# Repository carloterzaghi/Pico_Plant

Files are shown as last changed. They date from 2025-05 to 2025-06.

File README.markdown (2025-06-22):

# Sistema de Irrigação Inteligente com Raspberry Pi Pico

Um sistema embarcado para monitoramento de umidade do solo e controle automatizado de irrigação, utilizando o microcontrolador Raspberry Pi Pico.

## Visão Geral

Este projeto visa criar um sistema de irrigação eficiente e autônomo para plantas, especialmente projetado para uso doméstico ou em pequenos cultivos. Ele utiliza um sensor de umidade do solo capacitivo, criado previamente para somente esse projeto, para detectar o nível de umidade do solo e acionar uma bomba d'água conforme a necessidade. O sistema é construído sobre o Raspberry Pi Pico e programado em C/C++ utilizando o Pico SDK.

## Funcionalidades

* **Monitoramento Contínuo da Umidade do Solo**: Lê a tensão do sensor de umidade do solo a cada segundo para determinar o nível de umidade.
* **Controle Inteligente da Bomba D'água**: Ativa ou desativa a bomba automaticamente conforme o estado do solo, com lógica baseada em limiares de tensão.
* **Irrigação Otimizada**: Mantém a bomba ligada por 9 segundos quando necessário para garantir a hidratação adequada do solo.
* **Prevenção de Comandos Repetidos**: Uma *flag* (`motor_desligado`) evita o envio de comandos desnecessários à bomba, aumentando a eficiência e durabilidade.
* **Alimentação Estável do Sensor**: Utiliza PWM (Pulse Width Modulation) configurado com 100% de *duty cycle* no GPIO 2 para fornecer uma alimentação de 3.3V estáveis ao sensor de umidade, garantindo leituras precisas.
* **Comunicação Serial USB**: Fornece *feedback* em tempo real das leituras do sensor via comunicação serial para fins de depuração e monitoramento.
* **Feedback Visual**: Mostra rostos felizes ou tristes em um display OLED conforme o estado do solo.

## Hardware

### Esquema Elétrico do Controlador de Irrigação Inteligente
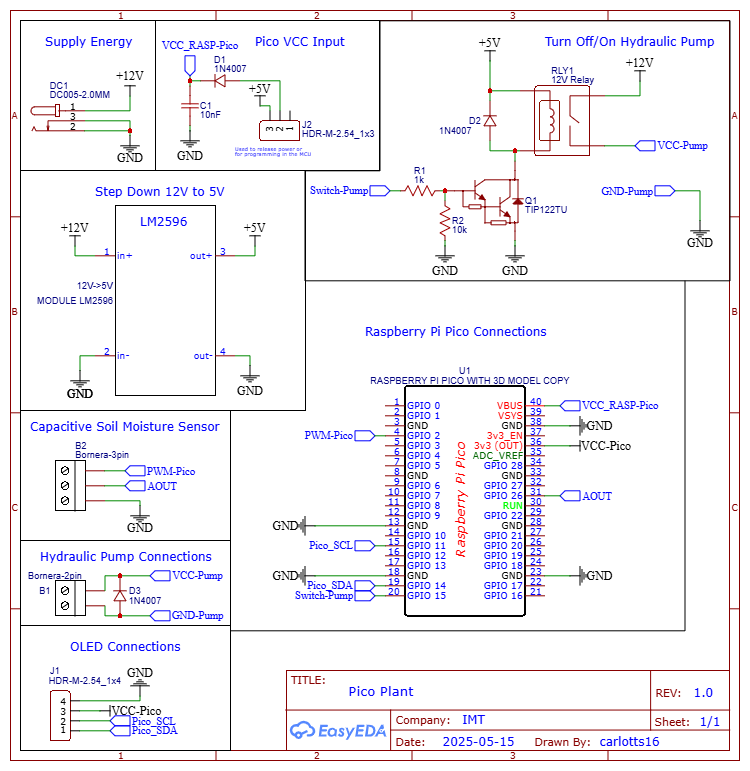
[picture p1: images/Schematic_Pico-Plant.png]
Esquema elétrico do controlador


### Exemplo de PCB do Controlador
#### Top Layer
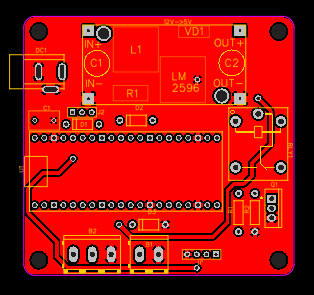
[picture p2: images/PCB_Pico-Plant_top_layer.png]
PCB Top Layer do controlador


#### Bottom Layer
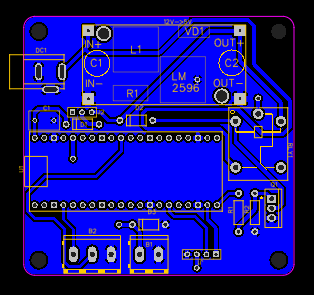
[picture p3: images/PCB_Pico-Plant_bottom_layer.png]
PCB Bottom Layer do controlador


### Esquema Elétrico do Sensor Capacitivo de Umidade do Solo
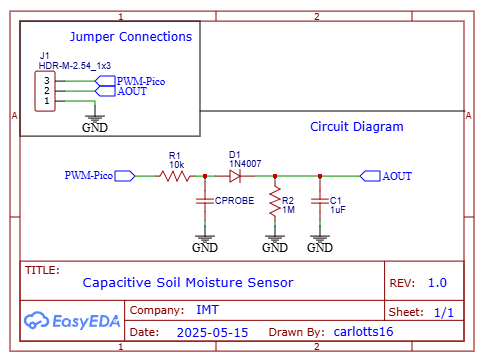
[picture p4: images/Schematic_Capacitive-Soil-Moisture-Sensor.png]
Esquema elétrico do sensor


### Exemplo de PCB do Sensor Capacitivo
#### Bottom Layer
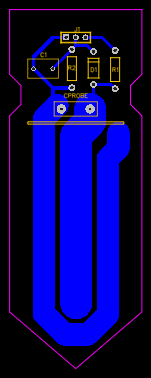
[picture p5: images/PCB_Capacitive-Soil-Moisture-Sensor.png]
PCB Bottom Layer do sensor


## Estrutura do Projeto

* `CMakeLists.txt`: Arquivo de configuração do CMake para construir o projeto.
* `main.c`: Contém a lógica principal do sistema, incluindo a inicialização, leitura do ADC, controle da bomba e exibição no OLED.
* `auxiliary_codes/pwm_code.c`: Implementa a função de configuração do PWM para alimentar o sensor.
* `auxiliary_codes/pwm_code.h`: Declaração da função de configuração do PWM.

## Lógica de Operação Detalhada

O sistema opera com base na leitura da tensão do sensor de umidade do solo, convertida pelo ADC do Raspberry Pi Pico. A lógica de irrigação é baseada em três faixas principais de tensão, conforme dados experimentais e a lógica implementada no código:

* **Valores de Referência**:
    * **Solo Muito Úmido**: Tensão < 0.58V **e** `motor_desligado == 0`
        * **Ação**: Liga a bomba por 9 segundos, mostra rosto triste no OLED.
    * **Solo Úmido**: Tensão >= 0.58V
        * **Ação**: Desliga a bomba, mostra rosto feliz no OLED, evita desligamento repetido (seta `motor_desligado = 1`).
    * **Solo Seco**: Tensão < 1.44V
        * **Ação**: Liga a bomba por 9 segundos, mostra rosto triste no OLED, libera novo ciclo (seta `motor_desligado = 0`).

* **Tabela de Referência da Umidade do Solo**:

| Tensão (V) | Água (mL) | Estado |
|---|---|---|
| 3.11-1.66  | 0-11 | Seco |
| 1.44-0.58  | 12-20 | Úmido Adequado |
| V <= 0.54  | mL >= 21  | Muito Úmido |

*Dados coletados:*

Materiais utilizados: `copo com 84757,03 mm^3` e `seringa com medidas de 1 em 1 mL`.

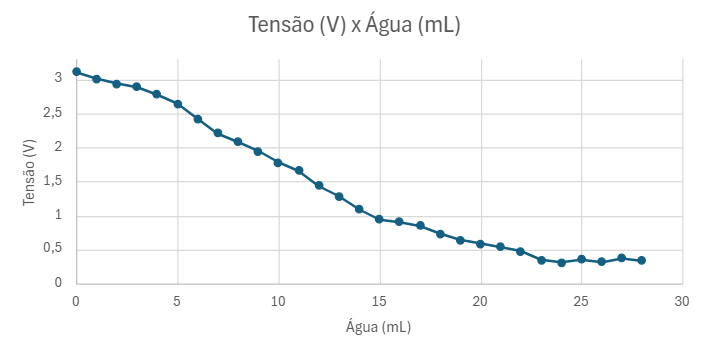
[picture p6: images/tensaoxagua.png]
Gráfico Tensão (V) x Água (mL)

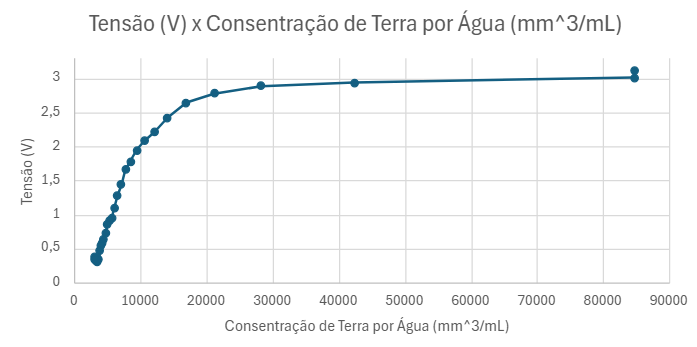
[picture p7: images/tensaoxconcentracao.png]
Gráfico Tensão (V) x Consentração de Terra por Água (mm^3/mL)


* **Prevenção de Ciclos**:  
A flag `motor_desligado` evita comandos repetidos de desligamento da bomba, melhorando a eficiência e durabilidade do sistema.

---

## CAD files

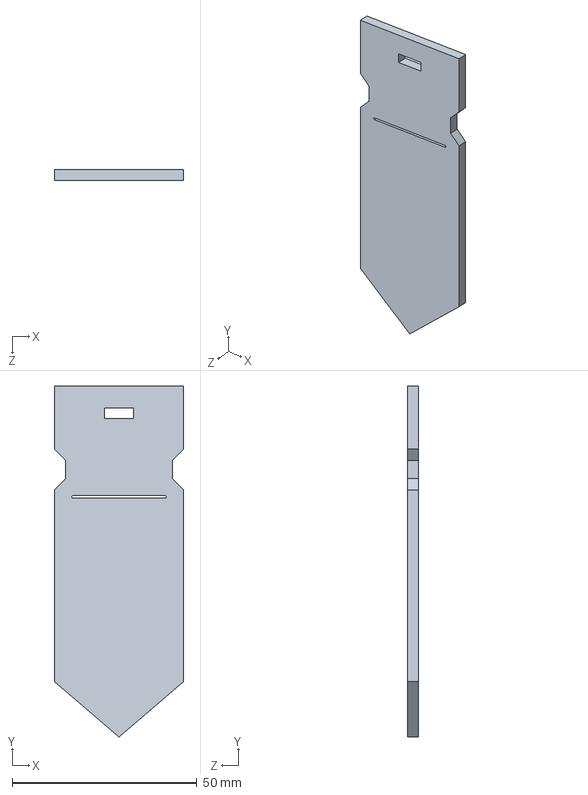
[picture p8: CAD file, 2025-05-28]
solid-parts/eletronic/PCB - Capacitive Soil Moisture Sensor.SLDPRT
35.0 x 95.0 x 3.00 mm

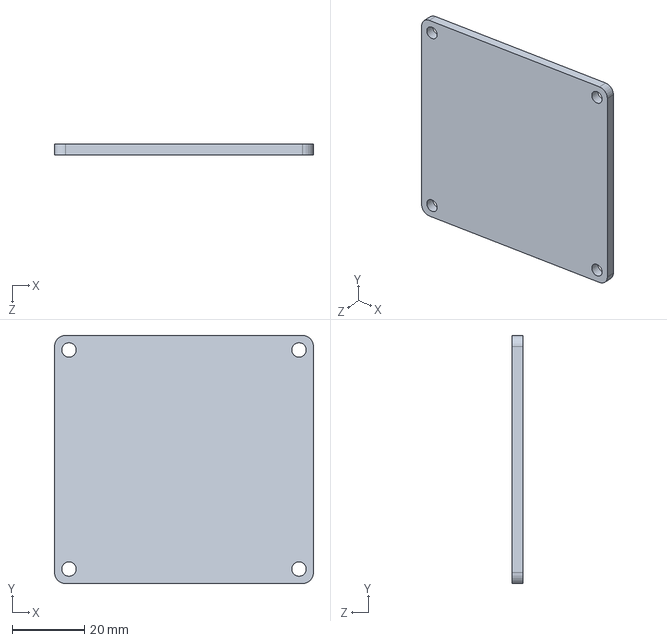
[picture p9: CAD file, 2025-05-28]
solid-parts/eletronic/PCB-Pico-Plant.SLDPRT
71.5 x 68.5 x 3.00 mm

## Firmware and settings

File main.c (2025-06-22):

// ===== INCLUSÃO DE BIBLIOTECAS =====
#include "pico/stdlib.h"                    // Funções básicas do Raspberry Pi Pico
#include "hardware/adc.h"                   // Interface para uso do ADC
#include "auxiliary_codes/pwm_code.h"       // Controle de alimentação via PWM
#include <stdio.h>                          // Entrada e saída padrão
#include "hardware/i2c.h"                   // Comunicação I2C
#include "hardware/gpio.h"                  // Controle de GPIOs
#include "auxiliary_codes/oled_ssd1306.h"   // Funções gráficas para display OLED

// ===== Definições de Hardware =====
#define SENSOR_ADC_GPIO 26     // GPIO 26 - Entrada analógica (ADC0) para sensor de umidade
#define SENSOR_PWR_GPIO 2      // GPIO 2  - Saída PWM para alimentação do sensor
#define PUMP_GPIO 15           // GPIO 15 - Saída digital para controle da bomba d'água
#define I2C_SDA 14             // GPIO 14 - Linha de dados I2C
#define I2C_SCL 11             // GPIO 11 - Linha de clock I2C

// ===== Parâmetros de Sistema =====
#define SOIL_MIN_VOLTAGE 1.44f      // Tensão mínima: >1.44V = mínimo para o solo estar úmido, depois do seco
#define SOIL_MAX_VOLTAGE 0.58f      // Tensão máxima: <0.58V = máximo para o solo estar úmido, antes de ficar muito úmido e não matar a planta

int main() {
    // === Inicialização do Sistema ===
    stdio_init_all();                      // Comunicação serial via USB
    printf("Inicializando faces animadas...\n");

    // --- Inicialização do barramento I2C ---
    i2c_init(I2C_PORT, 100 * 1000);        // Frequência I2C = 100kHz
    gpio_set_function(I2C_SDA, GPIO_FUNC_I2C);
    gpio_set_function(I2C_SCL, GPIO_FUNC_I2C);
    gpio_pull_up(I2C_SDA);                 // Pull-ups necessários para I2C
    gpio_pull_up(I2C_SCL);

    // --- Inicialização do Display OLED ---
    printf("Inicializando OLED...\n");
    sleep_ms(100);
    oled_init();
    printf("OLED inicializado! Iniciando animação...\n");

    // === Configuração de Hardware ===

    // --- Alimentação do sensor por PWM ---
    setup_pwm_power(SENSOR_PWR_GPIO);      // Estabiliza 3.3V via PWM para sensor analógico

    // --- Controle da bomba d'água ---
    gpio_init(PUMP_GPIO);                  
    gpio_set_dir(PUMP_GPIO, GPIO_OUT);     // Configura GPIO como saída

    // --- Inicialização do ADC ---
    adc_init();                            
    adc_gpio_init(SENSOR_ADC_GPIO);        // Ativa função analógica no GPIO 26
    adc_select_input(0);                   // Seleciona canal 0 do ADC

    // === Controle Inteligente ===
    int motor_desligado = 0;               // Flag de estado da bomba
                                           // 0 = bomba pode ser ligada
                                           // 1 = bomba já foi desligada após solo umedecido

    // === Loop Principal ===
    while (true) {
        // --- Leitura do sensor ---
        uint16_t leitura = adc_read();
        float tensao = leitura * 3.3f / 4095.0f; 
        printf("Leitura ADC: %d\tTensão: %.2f V\n", leitura, tensao);

        // --- Lógica de Irrigação ---
        if (tensao < SOIL_MAX_VOLTAGE && motor_desligado == 0) {
            // Condição: Menor que 0.58V e bomba não foi desligada
            printf("Mostrando rosto triste :(\n");
            draw_sad_face();                      // Exibe rosto triste no OLED
            gpio_put(PUMP_GPIO, 1);               // Liga a bomba
            sleep_ms(9000);                       // Irriga por 9 segundos
        } 
        else if (tensao >= SOIL_MAX_VOLTAGE) {
            // Condição: Maior ou igual a 0.58V
            printf("Mostrando rosto feliz :)\n");
            draw_happy_face();                    // Exibe rosto feliz no OLED
            gpio_put(PUMP_GPIO, 0);               // Desliga a bomba
            motor_desligado = 1;                  // Evita desligamento repetido
        }
        else if (tensao < SOIL_MIN_VOLTAGE) {
            // Condição: Menor que 1.44V
            printf("Mostrando rosto triste :(\n");
            draw_sad_face();                      // Exibe rosto triste no OLED
            motor_desligado = 0;
            gpio_put(PUMP_GPIO, 1);               // Liga a bomba
            sleep_ms(9000);                       // Irriga por 9 segundos
        }

        // Aguarda 1 segundo antes da próxima leitura
        sleep_ms(1000);                           
    }

    return 0;
}

/*
 * ===== RESUMO DO FUNCIONAMENTO =====
 * 
 * 1. INICIALIZAÇÃO:
 *    - PWM no GPIO 2 alimenta sensor de umidade
 *    - GPIO 15 configurado para controlar bomba
 *    - ADC configurado para ler GPIO 26
 * 
 * 2. CICLO DE MONITORAMENTO (a cada 1 segundo):
 *    - Lê tensão do sensor (0-3.3V)
 *    - Compara com os limiares definidos
 *    - Controla bomba e exibe rosto no OLED conforme a umidade
 * 
 * 3. ESTADOS DO SISTEMA (baseado na lógica atual):
 *    - SOLO MUITO ÚMIDO (tensão < 0.58V e motor_desligado == 0): Liga bomba por 9 segundos, mostra rosto triste
 *    - SOLO ÚMIDO (tensão >= 0.58V): Desliga bomba, mostra rosto feliz, evita desligamento repetido
 *    - SOLO SECO (tensão > 1.44V): Liga bomba por 9 segundos, mostra rosto triste, permite novo ciclo
 * 
 * 4. PREVENÇÃO DE CICLOS:
 *    - Flag 'motor_desligado' evita comandos repetidos de desligamento da bomba
 *    - Melhora eficiência e durabilidade do sistema
 * 
 * ===== TABELA DE REFERÊNCIA (Baseada em dados experimentais) =====
 * 
 * | Tensão (V) | Água (mL) | Estado           |
 * |------------|-----------|------------------|
 * | 3.11-1.66  | 0-11      | Seco             |
 * | 1.44-0.58  | 12-20     | Úmido Adequado   |
 * | V <= 0.54  | mL >= 21  | Muito Úmido      |
 * 
 * O sistema considera:
 * - SOLO MUITO ÚMIDO:     tensão < 0.58V e motor_desligado == 0 (bomba ON)
 * - SOLO ÚMIDO:           tensão >= 0.58V (bomba OFF)
 * - SOLO SECO:            tensão < 1.44V (bomba ON, libera novo ciclo)
 */

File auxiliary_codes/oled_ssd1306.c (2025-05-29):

#include "oled_ssd1306.h"
#include "hardware/i2c.h"
#include <string.h> 
#include <stdlib.h>   
#include <math.h>


// Buffer do display
static uint8_t oled_buffer[OLED_WIDTH * OLED_PAGES];

// Função para enviar comando
void oled_send_cmd(uint8_t cmd) {
    uint8_t buf[2] = {0x00, cmd};
    i2c_write_blocking(I2C_PORT, I2C_ADDR, buf, 2, false);
}

// Função para enviar dados
void oled_send_data(uint8_t *data, size_t len) {
    uint8_t buf[len + 1];
    buf[0] = 0x40;  // Data mode
    memcpy(buf + 1, data, len);
    i2c_write_blocking(I2C_PORT, I2C_ADDR, buf, len + 1, false);
}

// Inicializar o display
void oled_init() {
    oled_send_cmd(SSD1306_DISPLAY_OFF);
    oled_send_cmd(SSD1306_SET_DISPLAY_CLOCK_DIV);
    oled_send_cmd(0x80);
    oled_send_cmd(SSD1306_SET_MULTIPLEX);
    oled_send_cmd(OLED_HEIGHT - 1);
    oled_send_cmd(SSD1306_SET_DISPLAY_OFFSET);
    oled_send_cmd(0x00);
    oled_send_cmd(SSD1306_SET_START_LINE | 0x00);
    oled_send_cmd(SSD1306_CHARGE_PUMP);
    oled_send_cmd(0x14);
    oled_send_cmd(SSD1306_MEMORY_MODE);
    oled_send_cmd(0x00);
    oled_send_cmd(SSD1306_SEG_REMAP | 0x01);
    oled_send_cmd(SSD1306_COM_SCAN_DEC);
    oled_send_cmd(SSD1306_SET_COM_PINS);
    oled_send_cmd(0x12);
    oled_send_cmd(SSD1306_SET_CONTRAST);
    oled_send_cmd(0xCF);
    oled_send_cmd(SSD1306_SET_PRECHARGE);
    oled_send_cmd(0xF1);
    oled_send_cmd(SSD1306_SET_VCOM_DETECT);
    oled_send_cmd(0x40);
    oled_send_cmd(SSD1306_DISPLAY_ALL_ON_RESUME);
    oled_send_cmd(SSD1306_NORMAL_DISPLAY);
    oled_send_cmd(SSD1306_DISPLAY_ON);
}

// Limpar o display
void oled_clear() {
    memset(oled_buffer, 0, sizeof(oled_buffer));
}

// Atualizar o display
void oled_update() {
    oled_send_cmd(SSD1306_COLUMN_ADDR);
    oled_send_cmd(0);
    oled_send_cmd(OLED_WIDTH - 1);
    oled_send_cmd(SSD1306_PAGE_ADDR);
    oled_send_cmd(0);
    oled_send_cmd(OLED_PAGES - 1);
    
    oled_send_data(oled_buffer, sizeof(oled_buffer));
}

// Definir um pixel
void oled_set_pixel(int x, int y, bool on) {
    if (x >= 0 && x < OLED_WIDTH && y >= 0 && y < OLED_HEIGHT) {
        if (on) {
            oled_buffer[x + (y / 8) * OLED_WIDTH] |= (1 << (y % 8));
        } else {
            oled_buffer[x + (y / 8) * OLED_WIDTH] &= ~(1 << (y % 8));
        }
    }
}

// Desenhar círculo (algoritmo de Bresenham)
void oled_draw_circle(int cx, int cy, int radius, bool filled, bool on) {
    int x = 0;
    int y = radius;
    int d = 3 - 2 * radius;
    
    while (x <= y) {
        if (filled) {
            // Desenhar linhas horizontais para preencher
            for (int i = cx - x; i <= cx + x; i++) {
                oled_set_pixel(i, cy + y, on);
                oled_set_pixel(i, cy - y, on);
            }
            for (int i = cx - y; i <= cx + y; i++) {
                oled_set_pixel(i, cy + x, on);
                oled_set_pixel(i, cy - x, on);
            }
        } else {
            // Desenhar apenas o contorno
            oled_set_pixel(cx + x, cy + y, on);
            oled_set_pixel(cx - x, cy + y, on);
            oled_set_pixel(cx + x, cy - y, on);
            oled_set_pixel(cx - x, cy - y, on);
            oled_set_pixel(cx + y, cy + x, on);
            oled_set_pixel(cx - y, cy + x, on);
            oled_set_pixel(cx + y, cy - x, on);
            oled_set_pixel(cx - y, cy - x, on);
        }
        
        if (d < 0) {
            d = d + 4 * x + 6;
        } else {
            d = d + 4 * (x - y) + 10;
            y--;
        }
        x++;
    }
}

// Desenhar uma linha
void oled_draw_line(int x0, int y0, int x1, int y1, bool on) {
    int dx = abs(x1 - x0);
    int dy = abs(y1 - y0);
    int sx = x0 < x1 ? 1 : -1;
    int sy = y0 < y1 ? 1 : -1;
    int err = dx - dy;
    
    while (true) {
        oled_set_pixel(x0, y0, on);
        
        if (x0 == x1 && y0 == y1) break;
        
        int e2 = 2 * err;
        if (e2 > -dy) {
            err -= dy;
            x0 += sx;
        }
        if (e2 < dx) {
            err += dx;
            y0 += sy;
        }
    }
}

// Desenhar elipse (para olhos e boca)
void oled_draw_ellipse(int cx, int cy, int rx, int ry, bool filled, bool on) {
    int x = 0;
    int y = ry;
    int rx2 = rx * rx;
    int ry2 = ry * ry;
    int tworx2 = 2 * rx2;
    int twory2 = 2 * ry2;
    int p1 = ry2 - rx2 * ry + rx2 / 4;
    int dx = 0;
    int dy = tworx2 * y;
    
    // Região 1
    while (dx < dy) {
        if (filled) {
            for (int i = cx - x; i <= cx + x; i++) {
                oled_set_pixel(i, cy + y, on);
                oled_set_pixel(i, cy - y, on);
            }
        } else {
            oled_set_pixel(cx + x, cy + y, on);
            oled_set_pixel(cx - x, cy + y, on);
            oled_set_pixel(cx + x, cy - y, on);
            oled_set_pixel(cx - x, cy - y, on);
        }
        
        if (p1 < 0) {
            x++;
            dx += twory2;
            p1 += dx + ry2;
        } else {
            x++;
            y--;
            dx += twory2;
            dy -= tworx2;
            p1 += dx - dy + ry2;
        }
    }
    
    // Região 2
    int p2 = ry2 * (x + 0.5) * (x + 0.5) + rx2 * (y - 1) * (y - 1) - rx2 * ry2;
    while (y >= 0) {
        if (filled) {
            for (int i = cx - x; i <= cx + x; i++) {
                oled_set_pixel(i, cy + y, on);
                oled_set_pixel(i, cy - y, on);
            }
        } else {
            oled_set_pixel(cx + x, cy + y, on);
            oled_set_pixel(cx - x, cy + y, on);
            oled_set_pixel(cx + x, cy - y, on);
            oled_set_pixel(cx - x, cy - y, on);
        }
        
        if (p2 > 0) {
            y--;
            dy -= tworx2;
            p2 += rx2 - dy;
        } else {
            y--;
            x++;
            dx += twory2;
            dy -= tworx2;
            p2 += dx - dy + rx2;
        }
    }
}

// Desenhar arco para sorriso/tristeza
void oled_draw_arc(int cx, int cy, int radius, int start_angle, int end_angle, bool on) {
    for (int angle = start_angle; angle <= end_angle; angle++) {
        float rad = angle * M_PI / 180.0;
        int x = cx + (int)(radius * cos(rad));
        int y = cy + (int)(radius * sin(rad));
        oled_set_pixel(x, y, on);
        
        // Tornar a linha mais espessa
        oled_set_pixel(x + 1, y, on);
        oled_set_pixel(x, y + 1, on);
        oled_set_pixel(x + 1, y + 1, on);
    }
}
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
